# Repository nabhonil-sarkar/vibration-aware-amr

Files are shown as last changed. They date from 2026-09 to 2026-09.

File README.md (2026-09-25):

# Vibration-Aware Autonomous Mobile Robot

An Individual Major Project investigating whether payload-IMU feedback and bounded motion adaptation can reduce vibration during indoor transport of a representative fragile payload.

The robot is a **custom two-wheel differential-drive platform with a rear castor**, a proposed isolated payload deck and a **1 kg total carried-load target**. It is not a TurtleBot. A Raspberry Pi 5 is available; ROS 2 navigation and hardware integration are planned.

**Current stage: IMP Part B, prototype CAD and offline software testing. Physical construction and experimental validation have not been completed.**

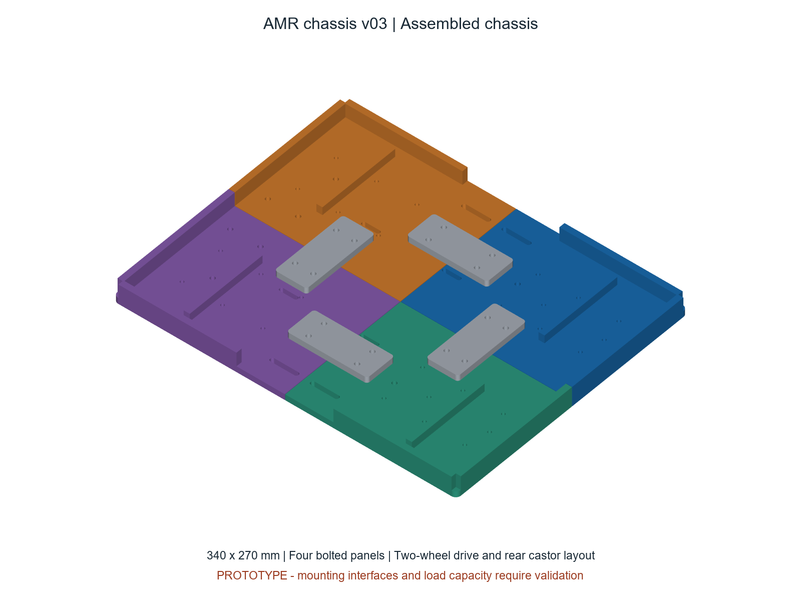
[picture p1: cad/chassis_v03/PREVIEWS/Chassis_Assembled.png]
Split chassis prototype


## What is here

| Folder | Contents | Evidence status |
| --- | --- | --- |
| [cad/chassis_v03](cad/chassis_v03) | Split chassis STEP assembly, individual STLs, CAD generator, previews and geometry checks | Validated file geometry; mounting fit and load capacity untested |
| [cad/concept_v02](cad/concept_v02) | Earlier Fusion assembly, STEP, coloured subsystem sheets and Fusion generator | Historical full-robot concept, not fabrication-ready |
| [software/vibration_aware_control](software/vibration_aware_control) | Python controller core, ROS 2 adapter, configuration, unit tests and synthetic demo | 20 offline tests passed; ROS runtime and hardware untested |
| [simulation/four_wheel_alternative](simulation/four_wheel_alternative) | MATLAB kinematics and analytical outputs for the earlier skid-steer alternative | Not the current two-wheel chassis model |
| [docs](docs) | Project status, next steps and repository scope | Planning documentation |

## Start here

- **Fusion:** import [AMR_Chassis_v03_Assembly.step](cad/chassis_v03/AMR_Chassis_v03_Assembly.step). The STEP preserves solids, not a Fusion feature timeline. Read the [chassis notes](cad/chassis_v03/READ_ME_FIRST.md) before editing or printing.
- **Printing:** the four main panels are 169.8 by 134.8 mm. A 220 by 220 mm usable bed is a provisional assumption. Start with the small hole-fit coupon after confirming the printer and material. Motor-specific mounts, castor mounting details and structural validation remain outstanding.
- **Controller:** run the ROS-independent tests with Python 3.10 or newer:

```sh
cd software/vibration_aware_control
python -m unittest discover -s tests -v
python -m vibration_aware_control.demo
```

The tests and CSV demo require only Python's standard library. Install `matplotlib` if a regenerated chart is wanted. The existing demo outputs are already included.

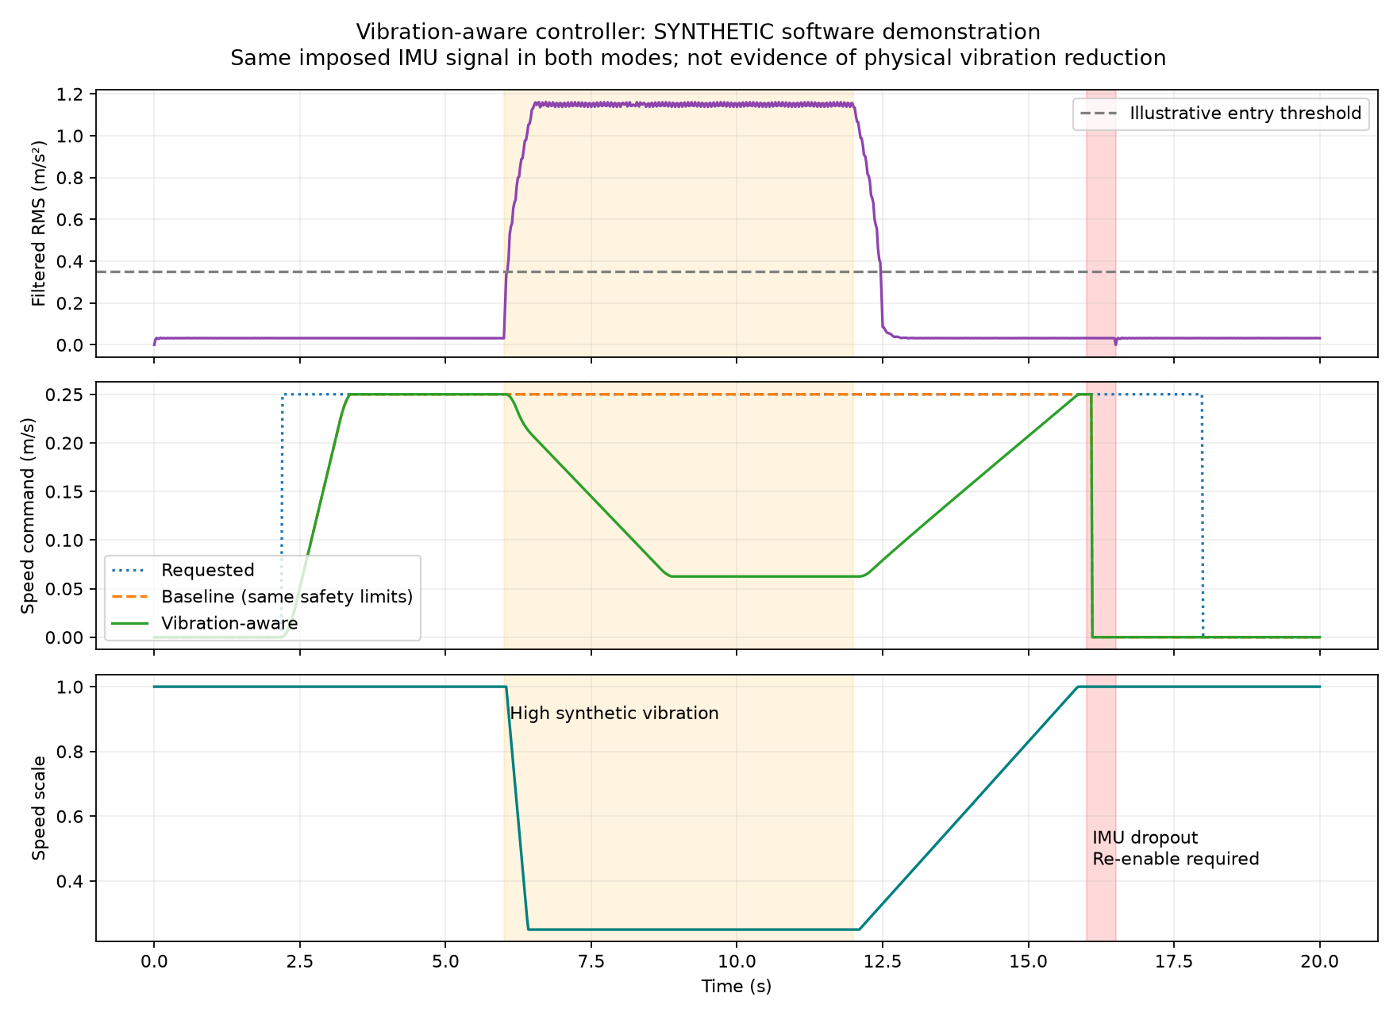
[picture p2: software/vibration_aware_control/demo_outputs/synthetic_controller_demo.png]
Synthetic controller response


Both demo modes receive the same imposed vibration input. The chart demonstrates command adaptation and a sensor-dropout stop; it does **not** demonstrate achieved physical vibration reduction.

## Planned architecture

Ubuntu 24.04 and ROS 2 Jazzy on the Pi 5; Gazebo Harmonic on the development PC; SLAM Toolbox, Nav2 with DWB, encoder/IMU odometry, ArUco docking and rosbag2 logging. A microcontroller handles wheel-speed control and an independent command watchdog. A hardwired emergency stop removes motor power independently of ROS.

The vibration-aware function adapts driving commands using payload acceleration. Passive elastomer isolation is planned. **Active vibration cancellation is not part of the core implementation.**

The planned experiment targets at least 20% lower RMS vibration with no more than 20% additional journey time. These are research targets, not results. Measurement definitions, gravity removal, matched-trial conditions and dataset counting must be fixed before trials.

## Before physical use

Confirm component dimensions, motor/driver ratings, battery and regulated power supplies, fasteners, print material, stability and laboratory risk controls. The CAD geometry checks are not FEA, proof-loading or a 1 kg capacity certification. The software is not safety-rated and must not be connected to powered wheels without supervised commissioning.

See [project status and next steps](docs/PROJECT_STATUS.md) for the current gaps. Academic submissions and personal forms are intentionally kept outside this repository. No new open-source licence has been selected.

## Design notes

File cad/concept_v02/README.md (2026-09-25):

# Historical Fusion V2 concept

This folder preserves the earlier complete robot concept, including Fusion and STEP files and balloon-labelled subsystem sheets. It is not a fabrication release.

The current chassis-base revision is in `../chassis_v03`. V2 includes placeholder purchased-part envelopes, a Pi 4 envelope and an older provisional 1500 g parameter; the implementation now has a Pi 5 available and a 1 kg total carried-load target. These historical differences must not be presented as verified current hardware.

The Fusion generator's output path is repository-relative in this copy. Its geometry has not otherwise been revised. It requires the Fusion Python API and must be run inside Fusion, not ordinary Python. Regenerated exports are ignored by Git until deliberately selected for publication.

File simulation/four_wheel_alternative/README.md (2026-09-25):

# Four-wheel skid-steer kinematics

This folder retains a preliminary base-MATLAB simulation for the earlier
four-wheel skid-steer alternative. The current chassis uses two driven wheels
and a rear castor. Do not use these results as validation of that chassis.

## Run the model

Open `skid_steer_kinematics.m` in MATLAB and select **Run**, or execute:

```matlab
run('skid_steer_kinematics.m')
```

The script creates an `outputs` folder containing:

- `skid_steer_trajectory.png`
- `skid_steer_motion_profiles.png`
- `skid_steer_summary.csv`
- `skid_steer_timeseries.csv`
- `skid_steer_results.mat`

## Model equations

The left-front and left-rear wheels share velocity `vL`, while the
right-front and right-rear wheels share velocity `vR`.

```text
linear velocity:  v = (vR + vL) / 2
ideal yaw rate:   omega = (vR - vL) / trackWidth
skid yaw rate:    omegaSkid = turnEfficiency * omega
wheel speed:      wheelOmega = sideVelocity / wheelRadius
```

## Current assumptions

- Chassis: 340 x 270 mm, carried over from the concept CAD.
- Wheel diameter: 70 mm.
- Centre-to-centre track width: 270 mm, derived from the provisional
  298 mm outside-to-outside CAD dimension and 28 mm wheel width.
- Wheelbase: 250 mm, provisional for this unselected four-wheel alternative.
- Turn efficiency: 0.80, used only to illustrate tyre-scrub effects.

These are preliminary simulation values, not experimental results. The turn
efficiency must later be estimated from commanded yaw versus measured yaw or
motion-capture/odometry data.

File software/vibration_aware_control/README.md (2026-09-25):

# Vibration-aware controller for Nabhonil's custom AMR

This is a first software prototype for your own robot, not a TurtleBot package. It is intended for ROS 2 Jazzy on Ubuntu 24.04 / Raspberry Pi 5. The calculation and demonstration also run on Windows without ROS, MATLAB, or special plugins.

**Status: offline core tests passed; ROS integration and physical robot operation are NOT yet tested. Do not connect directly to powered wheels before completing the commissioning checks below.**

## What it does

The payload IMU measures acceleration. The controller removes the constant part of that signal, filters high-frequency noise, and calculates how strongly the payload is shaking over a short window. When that value rises above a configurable threshold, it reduces the requested driving and turning speeds. It returns to normal gradually when the shaking settles.

It adapts motion; it does not move the isolators or provide active vibration cancellation. Wheel-speed PID, SLAM, navigation, IMU hardware drivers and motor control are separate systems and are not implemented here.

The intended command path is:

```text
Nav2 / selected teleop source -> vibration controller -> collision/safety gate
                                                     -> wheel controller / MCU
Payload IMU -----------------> vibration controller
Hardwired E-stop ------------------------------------> motor power cutoff
```

All motion sources must pass through the intended selection/safety chain. There must be only one final publisher to the drive command topic. Keep collision monitoring downstream so a stop cannot be overridden by this controller. A separate motor-command timeout on the MCU is essential: a crashed process cannot publish a stop. This is not a safety-rated controller.

## Files

| File | Purpose |
|---|---|
| `vibration_aware_control/core.py` | Filtering, RMS measurement, speed adaptation, command ramping and watchdog logic. No ROS dependency. |
| `vibration_aware_control/ros_node.py` | Receives IMU and velocity messages; publishes adapted velocity and status. |
| `config/controller.yaml` | Starting settings: thresholds, filters, limits, frames and timeouts. |
| `launch/vibration.launch.py` | Starts the ROS node with the configuration file. |
| `vibration_aware_control/demo.py` | Synthetic sensor demonstration with baseline/adaptive commands and a sensor dropout. |
| `tests/test_core.py` | Automated checks of normal operation, slowdown, recovery, stopping and invalid/missing data. |
| `demo_outputs/` | Generated CSV, summary and optional plot. These are synthetic, not experimental results. |
| `package.xml`, `setup.py`, `setup.cfg`, `resource/` | ROS/Python installation metadata. Replace the placeholder maintainer email before distribution. |

## Try it on Windows now

Open a terminal in this package folder (the one containing this README and `setup.py`). With Python 3.10 or newer:

```powershell
python -m unittest discover -s tests -v
python -m vibration_aware_control.demo
```

The core and CSV demo use only Python's standard library. For the optional PNG figure, install `matplotlib` and rerun:

```powershell
python -m pip install matplotlib
python -m vibration_aware_control.demo
```

In the demonstration, motion begins after a stationary warmup. High synthetic vibration is imposed from 6–12 s; the adaptive command slows while the baseline does not. At 16 s the IMU signal is interrupted; both modes stop and remain disabled even after data resumes. Both modes receive the SAME imposed vibration signal. The demo therefore demonstrates controller behaviour, not achieved vibration reduction or journey-time improvement.

## Algorithm and units

1. Receive approximately 100 acceleration samples/s in **m/s²** from the IMU attached to the payload deck. Not the chassis IMU.
2. Apply a first-order 1 Hz high-pass and 20 Hz low-pass filter per axis. These are gradual cutoffs, not a perfect rectangular frequency band. Configure the sensor's hardware anti-alias filter as well.
3. Calculate the vector RMS: `sqrt(mean(ax_filtered² + ay_filtered² + az_filtered²))` over the last 0.5 s. This is a sample-weighted estimate; near-uniform sampling is assumed.
4. Enter adaptation at 0.35 m/s², leave it below 0.20 m/s². This difference (hysteresis) reduces repeated switching.
5. During adaptation, scale = `1 - 0.75 * clamp((RMS - 0.20) / (1.00 - 0.20), 0, 1)`. Thus scale ranges from 1.0 to 0.25. Its fall/rise rates are separately limited.
6. Apply the same scale to linear and angular target velocities, then ramp the two outputs independently. Baseline mode disables vibration adaptation but retains the same base limits, input checks and watchdogs.

The example maximum speeds are 0.30 m/s and 0.60 rad/s. Acceleration/jerk requests are limited and reduced as the vibration scale falls. These are **command-shaping limits**, not guarantees about the physical acceleration or jerk of the robot/payload. Independent axis ramps can change turning curvature during transitions. Stops, exact-target clamps and hard maximum-speed clamps take precedence over jerk smoothing; abrupt input changes can therefore create jerk discontinuities. A falling acceleration limit is approached through the jerk limiter, not instantaneously imposed. Retune after measuring wheel response.

The minimum scale is a motion setting, NOT a declaration that any vibration level is safe. There is no validated fragile-payload damage threshold or shock-trip protection here. The 60 m/s² per-axis input guard catches implausible/out-of-range readings for this prototype and requires re-enable after a fault; it is not a calibrated impact detector or universal IMU saturation check.

## Assumptions and limitations

- Indoor, approximately level travel with a rigidly mounted payload IMU and limited tilt. A high-pass filter rejects constant gravity/bias; it **does not** fully compensate gravity during rotation and does not separate vibration from all commanded motion. Low-frequency motion below the cutoff is deliberately attenuated.
- No orientation quaternion is used in this version. If significant pitch/roll occurs, add calibrated attitude-based gravity compensation and validate the metric against a reference measurement. Do not label this metric full-band dynamic acceleration in reports.
- The accelerometer is already correctly scaled and calibrated by its driver. Sensor noise, mounting resonance, saturation and aliasing still need measurement. An IMU driver is NOT included.
- Samples arrive near 100 Hz. A minimum sample count rejects obviously slow streams, but transport jitter and dropped samples can still bias the RMS. Record and inspect actual timestamps/rate.
- ROS publishers use synchronized clocks, nonzero increasing timestamps and the expected frame IDs. Stamped commands must be expressed in `base_link`; no coordinate transformation is performed.
- The command interface is forward/reverse speed plus yaw rate. It can sit above a two-wheel differential drive or four-wheel skid-steer base. It does not assume wheel diameter/track or implement skid compensation. Those belong in the wheel controller.
- Slower travel is a hypothesis for reducing vibration, not a universal rule: resonances can make some lower speeds worse. Real trials must establish the useful speed range.
- Feedback reacts after vibration is measured. It cannot prevent the first impact and its filter/ramp delays must be considered. It does not replace passive isolation, retention, safe route selection or collision avoidance.
- No hardware-performance percentage is claimed. Your planned 20% RMS reduction / <=20% journey-time penalty remains a test objective.

## ROS 2 installation (on Ubuntu, not ordinary Windows Python)

Install ROS 2 Jazzy, colcon and rosdep first. Copy this complete `vibration_aware_control` folder into `~/amr_ws/src/`. Then:

```bash
source /opt/ros/jazzy/setup.bash
cd ~/amr_ws
rosdep install --from-paths src --ignore-src -r -y
colcon build --symlink-install --packages-select vibration_aware_control
source install/setup.bash
ros2 launch vibration_aware_control vibration.launch.py
```

All parameters are startup-only. Edit the YAML and restart while disarmed; changing parameters live is not supported. The launch file also accepts `params_file:=/absolute/path/controller.yaml`. For Gazebo, use `use_sim_time:=true` and make sure all publishers use the same ROS clock. Watchdogs remain wall-monotonic: pausing simulation disarms the controller, and resuming requires fresh data/warmup and manual re-enable.

### Interfaces

| Topic/service | Type | Direction |
|---|---|---|
| `/payload/imu` | `sensor_msgs/msg/Imu` | Input; acceleration in m/s², frame `payload_imu_link`, ~100 Hz |
| `/cmd_vel_requested` | `geometry_msgs/msg/TwistStamped` by default | Input; `base_link`, fresh command stream |
| `/cmd_vel_vibration` | Same velocity type as input | Output at 50 Hz; connect to downstream safety gate |
| `/vibration/status` | `std_msgs/msg/String` containing JSON | Output at 10 Hz: RMS, scale, state, speed, enabled flag |
| `/vibration/enable` | `std_srvs/srv/SetBool` | Explicit enable/disable |

Set `stamped_commands: false` only if the upstream AND downstream components require `Twist`. Unstamped commands lack header age checks; they still have arrival-time watchdogs. Nav2 Jazzy supports both types, so configure/remap all relevant publishers/subscribers consistently rather than assuming they match. The node rejects wrong frames, stale/duplicate stamps, unavailable acceleration and non-planar commands.

### First commissioning — wheels raised and motor power isolated initially

1. Check the hardwired E-stop, retention, wiring, fusing, independent MCU watchdog and downstream collision-stop path with your lab supervisor. Keep the controller's output disconnected from motor actuation while verifying interfaces.
2. Confirm IMU units, axes, timestamp, frame, noise and hardware sampling/filter settings. A stationary raw accelerometer that includes gravity typically reads approximately 9.81 m/s² in vector magnitude. Record a stationary dataset before tuning thresholds.
3. Publish the real payload IMU continuously and a continuous **zero** command stream. Wait at least 1.5 s for the filter to settle. Zero commands alone do not prove the robot is physically stationary: verify that separately.
4. Check `/vibration/status`. The controller starts disabled and requires fresh inputs and a zero requested command to enable:

```bash
ros2 topic echo /vibration/status
ros2 service call /vibration/enable std_srvs/srv/SetBool '{data: true}'
```

5. Observe the output with motor power still isolated. Test requested stop, unplugged IMU, stale command and process termination. Verify the downstream MCU stops if this process disappears. Never bypass a fault to make it move.
6. Only after those checks, test raised wheels at very low settings, then a clear supervised floor area with a non-fragile dummy load. Verify collision avoidance, braking distance and Nav2 behaviour under speed scaling.

To disable:

```bash
ros2 service call /vibration/enable std_srvs/srv/SetBool '{data: false}'
```

IMU silence beyond 0.10 s, command silence beyond 0.30 s, invalid data or a long control-loop gap disarms the prototype. A watchdog detection produces a zero command at the next running timer tick; it is not an instantaneous motor brake. Once recovered, send zero commands, allow the filter to settle as needed and explicitly re-enable. A fault does not automatically restart movement.

## How this should develop as the project progresses

1. Confirm the actual IMU model/driver and microcontroller. Integrate the payload IMU publisher; this package deliberately avoids inventing a hardware wiring/interface choice.
2. Record stationary and baseline route data with the actual dummy payload. Tune filter band/window to the mechanical vibration spectrum, distinguish noise from vibration and document why thresholds were chosen.
3. Measure speed tracking, stopping distance, low-speed stalling and isolator resonance. Revise speed/acceleration/jerk settings; coordinate scaling with Nav2 progress checking and collision monitoring.
4. Add validated gravity compensation if tilt matters, plus sensor-specific saturation checks and appropriate shock handling once requirements are known.
5. Run at least 10 matched baseline and 10 adaptive trips using the same payload, route, tyres, isolation and measurement settings. Interleave modes to reduce battery/floor-condition bias. For baseline, restart with `adaptive: false`; keep all safety and base motion limits identical.
6. Record raw IMU, requested/adapted/final motor commands, odometry and status with rosbag2. Calculate consistent whole-trip metrics offline: band-limited RMS, peaks, journey time, failures and variability. Controller rolling RMS/status is diagnostic, not a substitute for a full trial analysis. Do not claim success from the synthetic demo.

Example recording command (add the actual final motor-command topic):

```bash
ros2 bag record /payload/imu /cmd_vel_requested /cmd_vel_vibration /vibration/status /odom
```

## Verification and references

The automated tests exercise the ROS-independent core. ROS imports are syntax-checked only in the present Windows environment; a ROS 2 runtime/colcon build and real message-level integration test remain required on the Pi/Ubuntu system. The wrapper intentionally uses ordinary ROS messages and has no specific MCU dependency.

- [Nav2 Jazzy TwistSubscriber: configurable Twist/TwistStamped interface](https://api.nav2.org/nav2-jazzy/html/classnav2__util_1_1TwistSubscriber.html)
- [Nav2 Jazzy collision monitor configuration](https://docs.nav2.org/jazzy/configuration_and_development/configuration_guide/core_servers/collision_monitor/configuring_collision_monitor_node/)
- [Official sensor_msgs/Imu message definition](https://github.com/ros2/common_interfaces/blob/jazzy/sensor_msgs/msg/Imu.msg)

The reference design does not require a Codex plugin. Hardware testing requires your actual ROS 2 installation and IMU driver, not an AI plugin.

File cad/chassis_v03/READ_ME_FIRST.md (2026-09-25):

# AMR chassis v03 prototype

This is a new split, 3D-printable chassis-base design for Nabhonil Sarkar's custom vibration-aware robot. It follows the approved outline's two driven wheels and rear castor layout. It is not a TurtleBot chassis. Previous Fusion concept files and the approved outline have not been modified.

**Status: prototype geometry for review and fit testing, not a validated load-bearing design.** The 1 kg carried-load objective is a design requirement, not an achieved capacity. The complete robot mass is higher because the battery, motors, computers and structure also load the chassis.

## Which file to open

- `AMR_Chassis_v03_Assembly.step`: open/import this in Fusion to inspect the complete nine-part chassis assembly. STEP contains editable solid geometry, but does not recreate a native Fusion parametric feature timeline. Save a native Fusion copy after importing if required.
- `STEP`: individual solid parts, kept at their assembled coordinates for editing and comparison.
- `STL`: ten millimetre-scale mesh files, one per printed part including a test coupon. All are translated onto the print plane with their minimum Z at zero. Print each panel separately. STL is unitless internally: select millimetres and check its dimensions in the slicer.
- `PREVIEWS`: assembled, exploded and top-view pictures made from the actual generated geometry.
- `Print_Parts_List.csv`: quantities and measured geometry bounds; this is not a supplier purchasing list.
- `Mounting_Coordinates_mm.csv`: round-hole locations. The origin is at the assembled chassis centre, X points forward, Y points left and Z points up. These are proposed interfaces, not verified component dimensions.
- `Geometry_Checks.json`: solid validity, watertight-mesh, part-size and overlap checks. These are not structural or physical tests.
- `build_chassis.py`: regenerates the model using CadQuery 2.8. Dimensions and feature coordinates are defined in the source. Some dimensions are coupled to fixed feature coordinates: review all affected features when changing the envelope; this is not an arbitrary-size chassis configurator.

## Parts and geometry

The assembled footprint is 340 by 270 mm. Four panels each occupy approximately 169.8 by 134.8 mm, with a deliberate 0.4 mm gap at the two centre seams. The floor is 6 mm thick; outer rims rise another 14 mm. Internal ribs rise 8 mm above the floor. These provisional dimensions require print and stiffness evaluation.

Print one each of panels 01 to 04, joint plates 05 to 08, and rear castor adapter 09. The four top-mounted splice plates connect the panel seams. The castor adapter fits underneath the rear centre. Its four attachment holes match the chassis; the centre is intentionally blank until the actual castor's mounting pattern is known.

The provisional printer assumption is a 220 by 220 mm usable bed. Each part has been checked with a 5 mm allowance on each side for a brim. Confirm the real printer's usable area, excluded zones and nozzle/material configuration before slicing. No G-code is provided because the printer is unknown.

## Interfaces that still need confirmation

1. **Drive system:** the wheel/axle area is centred on X = 0. Side rims have a central 96 mm opening. Four 28 by 4.5 mm slots, centred at X = -20 and +20, Y = -112 and +112 mm, provide provisional motor-bracket attachment. Motor-specific brackets, shaft height, wheel offset, tyre clearance and fasteners are not yet designed. Do not assume these slots fit a selected motor.
2. **Rear castor:** the adapter is centred at X = -135, Y = 0. Its chassis attachment holes are X = -150/-120 and Y = -22/+22 mm. Add the purchased castor's pattern only after checking that it does not collide with these fixing holes. Castor overall height, wheel diameter, swivel sweep and ground clearance remain unresolved.
3. **Payload supports:** four 4.5 mm holes at X = -125/+55 and Y = -72/+72 mm provide proposed riser locations. The front pair differs from the old concept's X = +35 mm to clear the new seam plates. Risers, elastomer mounts and the elevated deck are not included in this base package and must be updated together.
4. **Electronics and rigid sensor bridge:** general 3.4 mm holes and provisional bridge points allow separate mounting plates or standoffs. They are not direct Raspberry Pi 5 or STM32 footprints. Verify board clearances, cooling, connectors and electrical insulation.
5. **Battery:** four 18 by 4 mm strap slots are centred at X = -70/+10 and Y = -48/+48 mm. The battery needs a protected tray/retention arrangement that clears the top seam plates and all fasteners. Verify the selected battery dimensions; no battery tray is included.
6. **Stability and guards:** verify the assembled centre of gravity stays within the driven-wheel/castor support triangle, including braking and turns. Front anti-tip supports, bumpers and wheel guards shown in the earlier concept are not supplied by this base package. Their interfaces require a later revision before powered operation.

## Start with the small fit coupon

`00_Hole_and_Slot_Fit_Coupon.stl` is 70 by 32 by 6 mm. With its long axis horizontal, the round holes run left to right as 3.4, 4.3, 4.5 and 4.7 mm, followed by a 15 by 4.5 mm slot. Test it using the intended printer, material and fasteners. Measure the printed features and adjust the design or slicer compensation if required. The coupon checks dimensional fit only, not chassis strength.

## Provisional assembly sequence

1. Confirm the motor/wheel and castor interfaces, print-bed size, material, and workshop approval. Resolve any mounting changes before a full print.
2. Slice with each supplied flat bottom on the bed. Inspect the preview for complete walls, floors, holes and no unsupported features. Use the printer/material supplier's profile and record all settings. Wall count, infill and layer height remain to be selected and tested; no load rating is inferred from these files.
3. Label the four panels and bring them together around the 0.4 mm centre gaps. Install the four splice plates on top. Add the castor adapter underneath the rear centre.
4. The five attachment groups use 20 M4 through-bolts in total, with nuts and washers. M4 x 20 mm is a preliminary length for the 12 mm plastic stack; check actual washer/nut thickness and thread protrusion before purchase. Use washers to spread contact pressure and tighten without crushing the print. No torque value is specified.
5. With power disconnected, check seam alignment, fastener access, rocking, mount deflection and cracking. Review staged static loading with the supervisor/lab technician, including the full robot mass and secured carried load. Revise weak joints or panels before powered testing.

No motor mounts, electronics, castor, payload deck, bolts, washers or nuts are represented as purchased/installed hardware. Printing and assembly have not been performed.

## Validation boundary

The automated checks establish that the nine assembly parts are valid single solids, exported STLs are closed and consistently wound, a STEP reimport preserves nine solids, and assembled printed parts do not overlap by positive volume. Contact between joint plates and floors is intentional. The coupon mesh is also checked for closure.

The checks do not establish material properties, layer adhesion, print quality, load capacity, fatigue life, vibration behaviour, fastener pull-through resistance, stability, wheel clearance or compatibility with actual hardware. No FEA has been completed.

The CAD source uses the documented STEP/STL export functions: [CadQuery import and export documentation](https://cadquery.readthedocs.io/en/latest/importexport.html).

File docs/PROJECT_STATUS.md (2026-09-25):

# Project status

Snapshot: 25 September 2026.

The outline has been approved. At the 23 September meeting, the student and supervisor agreed to use the outline's parts list and try a 3D-printed chassis. This repository records subsequent engineering work without modifying the submitted outline.

## Completed artefacts

- Fusion V2 full-robot concept and three coloured subsystem sheets.
- A preliminary MATLAB four-wheel alternative study with simulated outputs.
- A ROS-independent vibration-aware control core and synthetic demonstration, with 20 passing unit tests.
- A ROS 2 adapter and launch/configuration files, not yet runtime-tested.
- V03 split chassis geometry: four panels, four splice plates, a castor adapter blank and a separate fit coupon. Closed meshes, valid solids, nine assembly solids after STEP reimport, and no positive-volume overlap between assembled printed parts were checked.

No physical assembly, vibration improvement, docking performance or autonomous navigation result is claimed.

## Decisions and unresolved interfaces

- Use two driven wheels and a rear castor as the working build basis. The four-wheel MATLAB model is retained as an alternative study, not quietly treated as the same robot.
- Pi 5 availability differs from the Pi 4 named in the historical outline and concept. Update mounting, power and interface documentation during implementation.
- The current carried-load target is 1 kg, including the carrier and secured dummy payload. Earlier concept parameters contain provisional values such as 1500 g; they are not the current requirement.
- V03 is a chassis-base package, not a finished robot. Motor brackets, castor-specific holes, payload risers/deck, battery tray, guards and anti-tip interfaces still need verified hardware geometry.
- The V03 front payload-support provision moved from the old concept's X = +35 mm to +55 mm to clear splice plates. Coordinate the deck revision accordingly.
- Printer, material, motor stall current, driver, battery/charger/regulators and exact MCU remain to be verified before fabrication or purchase.

## Next implementation sequence

1. Verify the BOM against lab stock and supplier specifications, including complete power compatibility and long-lead items.
2. Confirm printer access and build area; print and measure the fit coupon, then release a chassis revision with verified interfaces.
3. Review risk controls and assemble the chassis, fused power system, independent motor E-stop and encoder-controlled drive.
4. Validate IMU acquisition, timing, units and calibration. Integrate odometry and the robot model before navigation.
5. Configure ROS 2/Gazebo, SLAM and Nav2, then integrate motion adaptation and visual docking.
6. Run controlled trials and report measured outcomes and failure modes.

This dependency chain protects the critical path from procurement and chassis fabrication through safe drive integration to sensing and experimental evidence. Detailed dates need to be agreed for Part B; the historical outline schedule is not evidence that those milestones are complete.

## Experimental clarifications to resolve

- Define the research question and the final whole-trial RMS/peak metrics.
- Validate gravity removal and filtering. The current controller uses a 0.5-second rolling vector RMS after first-order 1 Hz high-pass and 20 Hz low-pass filters, which is not full tilt compensation or a whole-trial metric.
- Specify unique vibration and integrated trial counts and declare any overlap.
- Match payload, route, nominal limits, tyres, isolation and other relevant conditions between baseline and adaptive modes.
- Define docking position error by absolute distance and orientation error by absolute wrapped angle against an independent reference.
- Select elastomers from supported mass, mechanical properties and measured response; do not infer isolation performance from appearance.
- Strengthen vibration/isolation sources, correct the Gazebo reference to Harmonic in future reports, and avoid treating 0.5g as a universal safety limit.

MPPI, a custom dashboard and a powered latch remain stretch objectives. Active cancellation is outside the core scope.

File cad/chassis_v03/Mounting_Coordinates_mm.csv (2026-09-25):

Purpose | X mm | Y mm | Diameter mm | Status
X seam joints | -24 | -79 | 4.5 | Verify hardware fit; joint geometry matched internally
X seam joints | -24 | -61 | 4.5 | Verify hardware fit; joint geometry matched internally
X seam joints | 24 | -79 | 4.5 | Verify hardware fit; joint geometry matched internally
X seam joints | 24 | -61 | 4.5 | Verify hardware fit; joint geometry matched internally
X seam joints | -24 | 61 | 4.5 | Verify hardware fit; joint geometry matched internally
X seam joints | -24 | 79 | 4.5 | Verify hardware fit; joint geometry matched internally
X seam joints | 24 | 61 | 4.5 | Verify hardware fit; joint geometry matched internally
X seam joints | 24 | 79 | 4.5 | Verify hardware fit; joint geometry matched internally
Y seam joints | -84 | -24 | 4.5 | Verify hardware fit; joint geometry matched internally
Y seam joints | -84 | 24 | 4.5 | Verify hardware fit; joint geometry matched internally
Y seam joints | -66 | -24 | 4.5 | Verify hardware fit; joint geometry matched internally
Y seam joints | -66 | 24 | 4.5 | Verify hardware fit; joint geometry matched internally
Y seam joints | 66 | -24 | 4.5 | Verify hardware fit; joint geometry matched internally
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

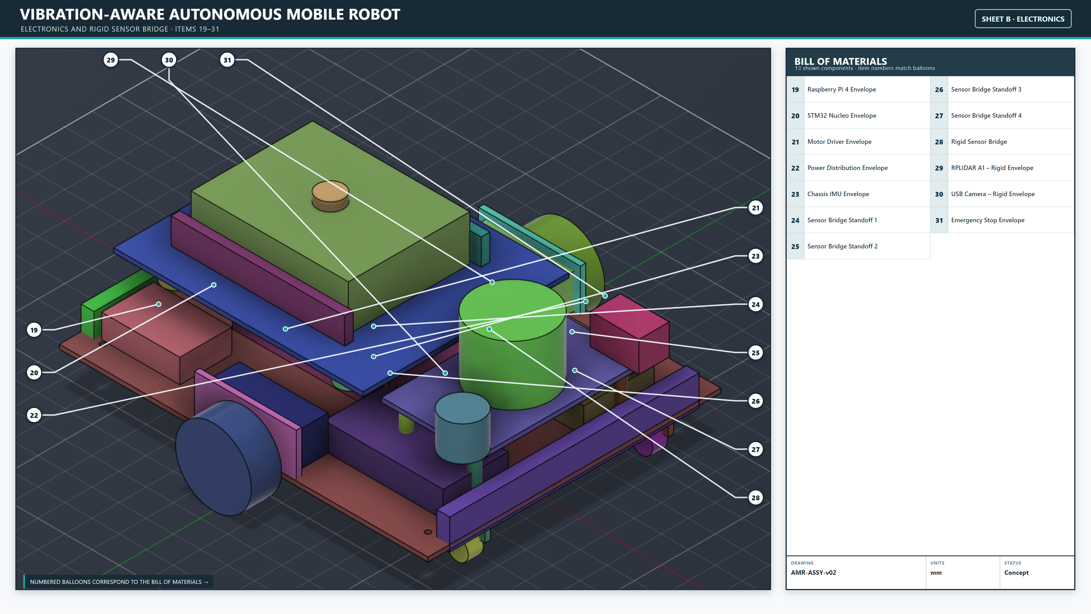
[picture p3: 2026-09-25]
cad/concept_v02/Vibration_Aware_AMR_Concept_v02_Ballooned_Sheet_B_Electronics.png

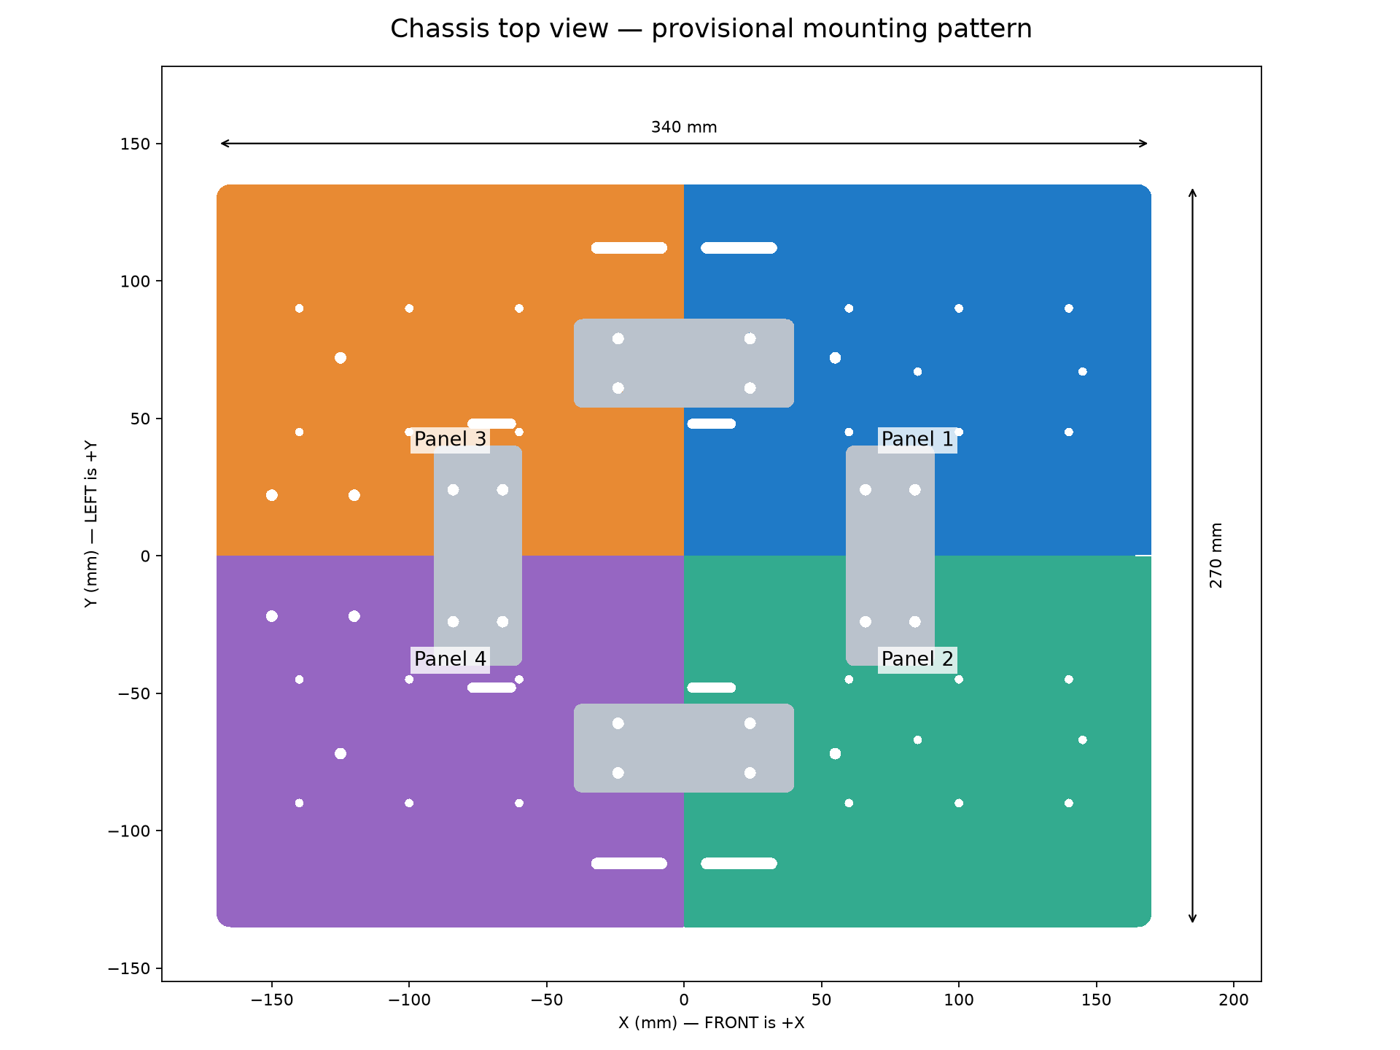
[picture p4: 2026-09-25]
cad/chassis_v03/PREVIEWS/Chassis_Top_View.png

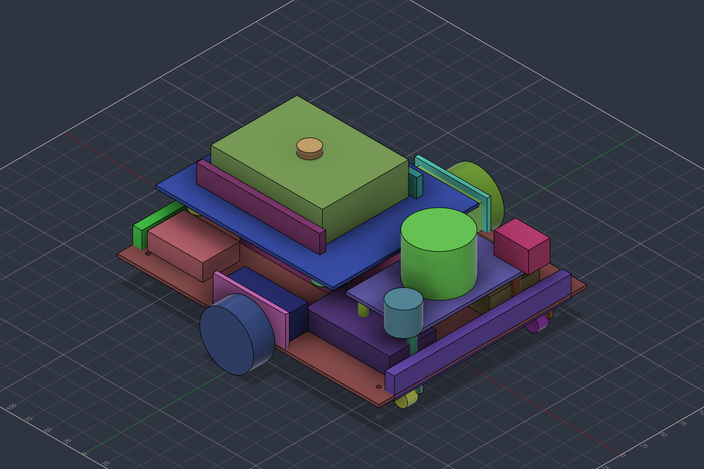
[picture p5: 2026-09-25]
cad/concept_v02/Vibration_Aware_AMR_Concept_v02_Colored.png

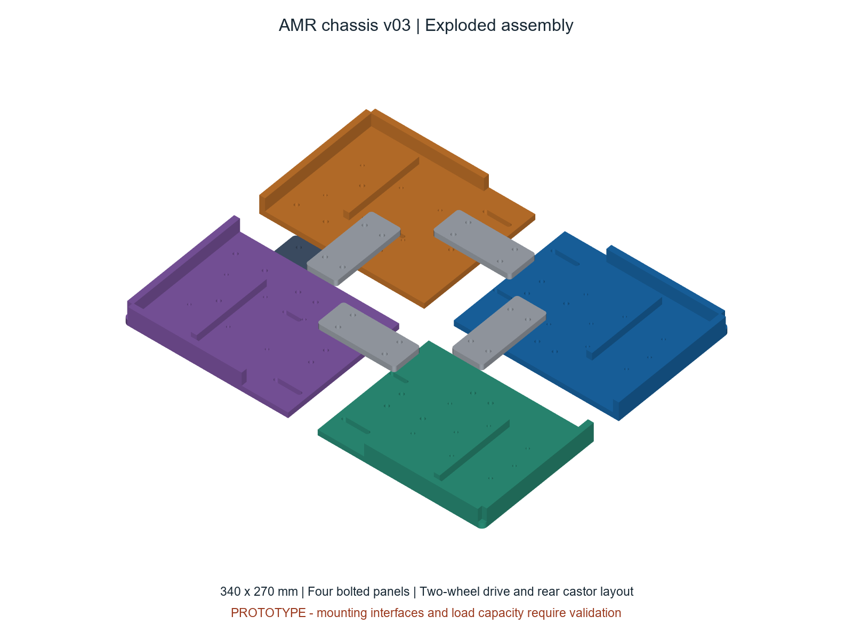
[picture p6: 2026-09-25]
cad/chassis_v03/PREVIEWS/Chassis_Exploded.png

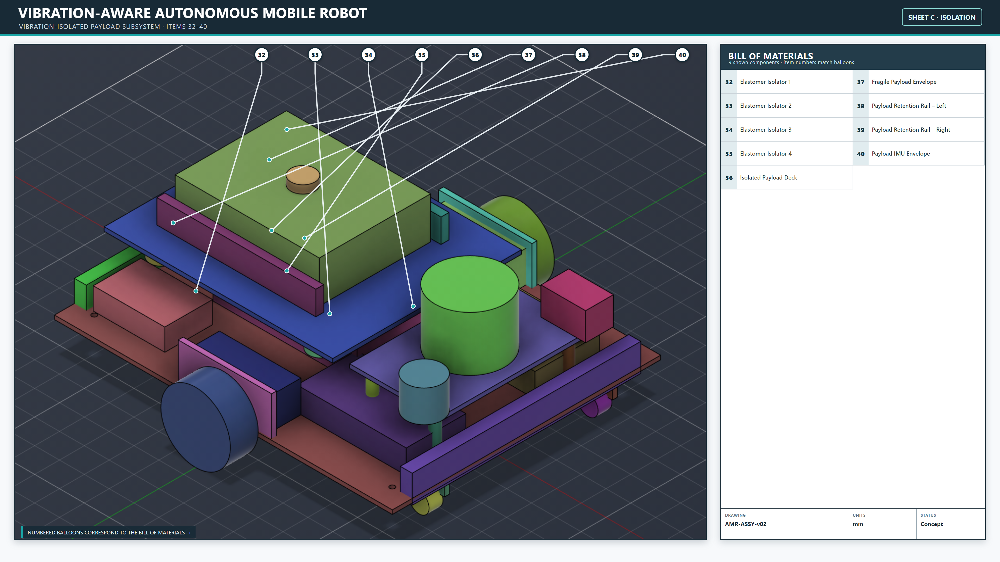
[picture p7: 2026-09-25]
cad/concept_v02/Vibration_Aware_AMR_Concept_v02_Ballooned_Sheet_C_Isolation.png

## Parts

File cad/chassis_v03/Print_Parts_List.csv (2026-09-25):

Part | Quantity | X mm | Y mm | Z mm | Status
01_Front_Left_Panel | 1 | 169.8 | 134.8 | 20.0 | Provisional prototype
02_Front_Right_Panel | 1 | 169.8 | 134.8 | 20.0 | Provisional prototype
03_Rear_Left_Panel | 1 | 169.8 | 134.8 | 20.0 | Provisional prototype
04_Rear_Right_Panel | 1 | 169.8 | 134.8 | 20.0 | Provisional prototype
05_Transverse_Joint_Plate | 1 | 80.0 | 32.0 | 6.0 | Provisional prototype
06_Transverse_Joint_Plate | 1 | 80.0 | 32.0 | 6.0 | Provisional prototype
07_Longitudinal_Joint_Plate | 1 | 32.0 | 80.0 | 6.0 | Provisional prototype
08_Longitudinal_Joint_Plate | 1 | 32.0 | 80.0 | 6.0 | Provisional prototype
09_Rear_Castor_Adapter_Blank | 1 | 54.0 | 64.0 | 6.0 | Provisional prototype
00_Hole_and_Slot_Fit_Coupon | 1 | 70 | 32 | 6 | Print and measure first

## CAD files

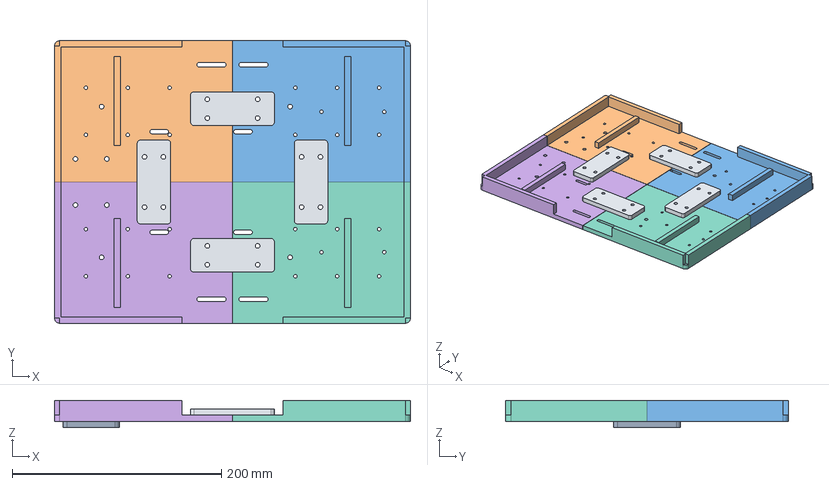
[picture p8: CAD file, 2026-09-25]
cad/chassis_v03/AMR_Chassis_v03_Assembly.step
340.0 x 270.0 x 26.0 mm
01_Front_Left_Panel
02_Front_Right_Panel
03_Rear_Left_Panel
04_Rear_Right_Panel
05_Transverse_Joint_Plate
06_Transverse_Joint_Plate
07_Longitudinal_Joint_Plate
08_Longitudinal_Joint_Plate
09_Rear_Castor_Adapter_Blank

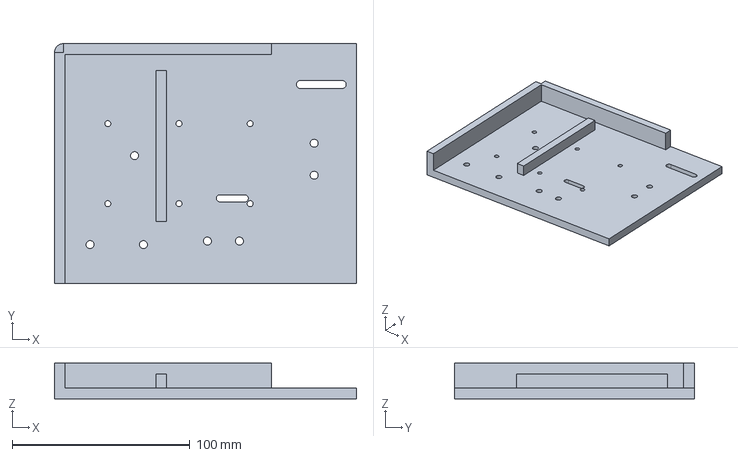
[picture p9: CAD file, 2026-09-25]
cad/chassis_v03/STEP/03_Rear_Left_Panel.step
169.8 x 134.8 x 20.0 mm

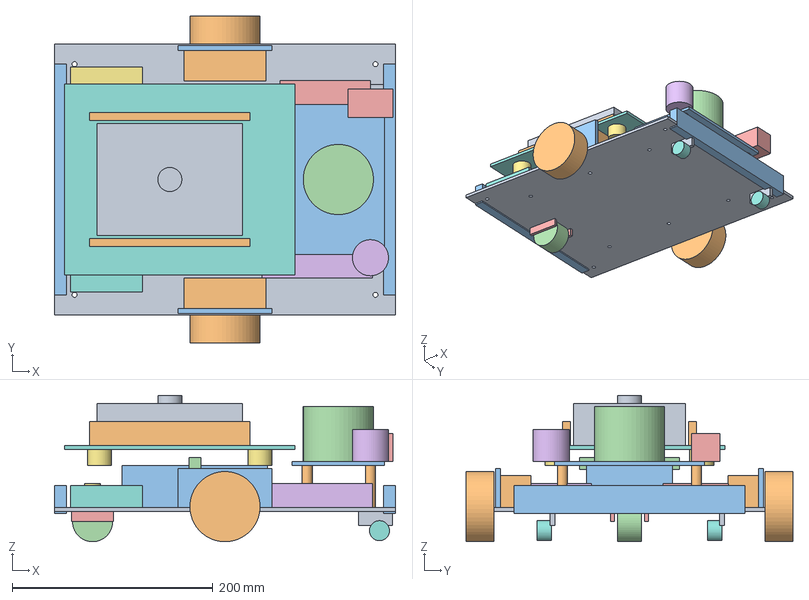
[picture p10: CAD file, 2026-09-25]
cad/concept_v02/Vibration_Aware_AMR_Concept_v02.step
340.0 x 326.0 x 146.0 mm

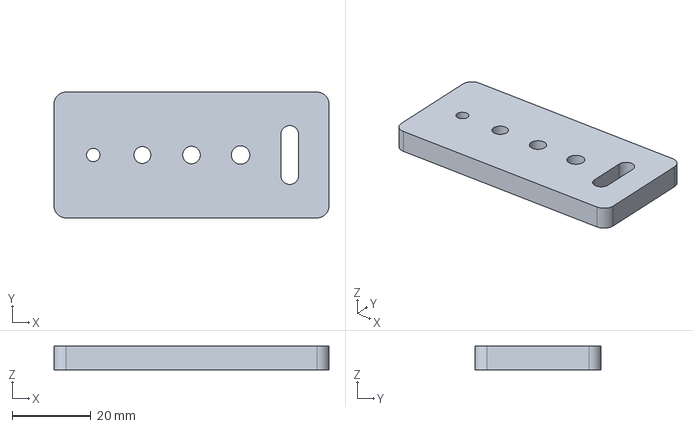
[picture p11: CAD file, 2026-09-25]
cad/chassis_v03/STEP/00_Hole_and_Slot_Fit_Coupon.step
70.0 x 32.0 x 6.00 mm

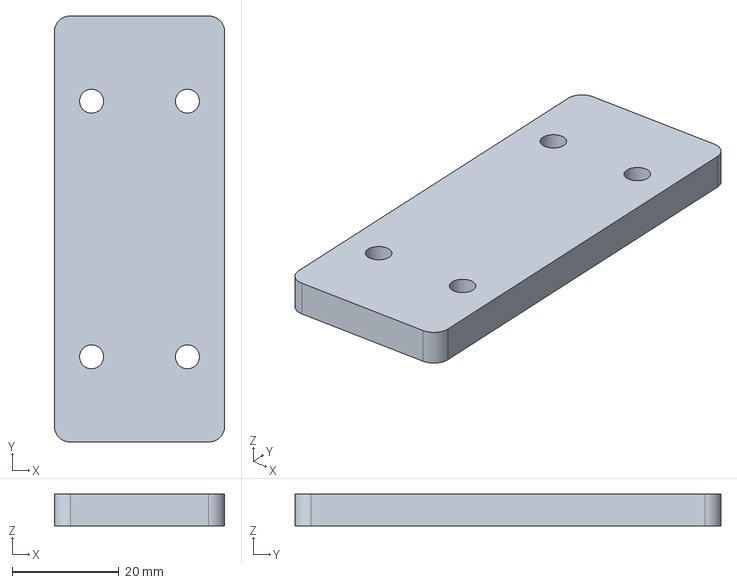
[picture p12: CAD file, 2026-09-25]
cad/chassis_v03/STEP/08_Longitudinal_Joint_Plate.step
32.0 x 80.0 x 6.00 mm

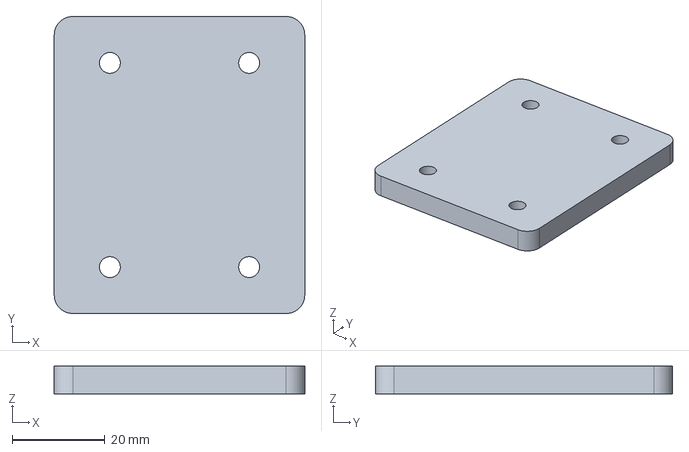
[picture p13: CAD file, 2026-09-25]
cad/chassis_v03/STEP/09_Rear_Castor_Adapter_Blank.step
54.0 x 64.0 x 6.00 mm

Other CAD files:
cad/chassis_v03/STEP/07_Longitudinal_Joint_Plate.step
cad/chassis_v03/STEP/02_Front_Right_Panel.step
cad/chassis_v03/STEP/04_Rear_Right_Panel.step
cad/chassis_v03/STEP/06_Transverse_Joint_Plate.step
cad/chassis_v03/STEP/01_Front_Left_Panel.step
cad/chassis_v03/STEP/05_Transverse_Joint_Plate.step
cad/chassis_v03/STL/00_Hole_and_Slot_Fit_Coupon.stl
cad/chassis_v03/STL/01_Front_Left_Panel.stl
cad/chassis_v03/STL/02_Front_Right_Panel.stl
cad/chassis_v03/STL/03_Rear_Left_Panel.stl
cad/chassis_v03/STL/04_Rear_Right_Panel.stl
cad/chassis_v03/STL/05_Transverse_Joint_Plate.stl
cad/chassis_v03/STL/06_Transverse_Joint_Plate.stl
cad/chassis_v03/STL/07_Longitudinal_Joint_Plate.stl
cad/chassis_v03/STL/08_Longitudinal_Joint_Plate.stl
cad/chassis_v03/STL/09_Rear_Castor_Adapter_Blank.stl
cad/concept_v02/Vibration_Aware_AMR_Concept_v02.f3d

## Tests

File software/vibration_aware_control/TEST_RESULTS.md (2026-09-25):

# Verification — 23 September 2026

- Windows, Python 3.12 bundled runtime.
- `python -m unittest discover -s tests -v`: **20 tests passed**.
- `python -m compileall -q vibration_aware_control launch`: passed Python syntax compilation.
- Synthetic demonstration executed and CSV, JSON and PNG generated; plot visually inspected.
- Synthetic peak filtered RMS: 1.16147 m/s²; minimum requested speed scale: 0.25.
- IMU dropout detected; adapted output remained zero after dropout and subsequent sensor recovery without re-enable.
- ROS `rclpy` is not installed in this environment. ROS node imports/execution, colcon installation, topic QoS/interoperability, launch and actual hardware behaviour have **not** been runtime-tested.

Tests cover startup disabled, warmup, rejection of low sensor rate, constant-gravity rejection, normal speed, vibration slowdown/recovery, baseline mode, stale IMU, stale commands, non-finite inputs, immediate commanded stop, enabling only with zero commands, reverse motion, proportional velocity caps, backwards IMU time, delayed control loop, initial acceleration/jerk ramp, randomized output bounds, parameter validation and the synthetic dropout scenario.

These results establish software-core behaviour under the included inputs. They do not establish real-time guarantees, general closed-loop stability, collision safety, payload protection or achieved vibration reduction. The prototype is not ready for unsupervised physical operation.

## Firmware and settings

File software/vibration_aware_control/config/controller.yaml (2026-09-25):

vibration_controller:
  ros__parameters:
    # Illustrative bench-test settings, NOT validated fragile-payload limits.
    adaptive: true
    stamped_commands: true
    imu_frame: payload_imu_link
    command_frame: base_link
    max_header_age_s: 0.15
    highpass_hz: 1.0
    lowpass_hz: 20.0
    window_s: 0.5
    warmup_s: 1.5
    minimum_samples: 30
    imu_timeout_s: 0.10
    command_timeout_s: 0.30
    loop_timeout_s: 0.10
    rms_release: 0.20
    rms_enter: 0.35
    rms_full: 1.00
    minimum_scale: 0.25
    scale_fall_per_s: 2.0
    scale_rise_per_s: 0.20
    max_linear: 0.30
    max_angular: 0.60
    max_linear_accel: 0.25
    max_angular_accel: 0.60
    max_linear_jerk: 1.0
    max_angular_jerk: 2.0
    max_accel_component: 60.0
